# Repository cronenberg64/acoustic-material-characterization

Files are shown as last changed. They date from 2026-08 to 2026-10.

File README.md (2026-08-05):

# Acoustic Material Characterization

This repository contains the software and firmware pipeline for characterizing material properties (such as density and Young's modulus) by analyzing acoustic impact sounds. 

The system relies on a physical testing rig (an ESP32-controlled solenoid) to strike material samples. The resulting acoustic waveform is captured, processed using physics-based modal feature extraction (identifying resonant frequencies and damping coefficients), and passed through a machine learning classifier to predict the material's properties.

## Scientific Objectives
This project bridges the gap between robotic perception (which currently predicts categorical labels under controlled contact) and non-destructive testing (which predicts continuous physical properties using expensive lab apparatus). Our **headline objective** is to prove that a robot can predict continuous physical properties (Density and Young's Modulus) from acoustic impacts, robust to real-world variations in contact location and force.

**Research Questions:**
- **RQ1:** Can we perform accurate property regression (Density, Stiffness) under a leave-one-sample-out evaluation?
- **RQ2:** How well does property estimation generalize across contact variation (held-out force levels and held-out strike positions)?
- **RQ3:** Which acoustic feature families (modal vs. generic) are most resilient to contact variation?

## Getting Started

This project uses `uv` for lightning-fast Python package management. 

### 1. Install Dependencies
```bash
uv sync
```

### 2. Run the Machine Learning Harness
You can test the machine learning pipeline (Random Forest, K-Nearest Neighbors, Ridge Regression, etc.) without needing the physical rig.

**To run on perfectly synthesized acoustic data:**
```bash
uv run python -m ame.models.run_all --dataset synthetic
```

**To run a sanity check on real-world impact data (RealImpact Dataset):**
First, download and extract the RealImpact zip files into `RealImpact/dataset/`. Then run:
```bash
uv run python src/ame/data/import_real_impact.py --dir RealImpact/dataset
uv run python -m ame.models.run_all --dataset internet
```

## Data Acquisition (DAQ)

Once the physical rig is built (ESP32 + Solenoid + Microphone), you can use the DAQ scripts to collect real acoustic samples.

### Calibrate the Solenoid
Determines the correct pulse widths to achieve 5N, 10N, and 15N impact forces.
```bash
uv run python src/ame/daq/calibrate.py --port /dev/cu.usbserial-XXXX
```

### Run an Acquisition Session
Automatically iterates through sample IDs, strike locations, and force levels to build a comprehensive dataset.
```bash
uv run python src/ame/daq/acquire.py --port /dev/cu.usbserial-XXXX
```
*(Note: If no ESP32 is connected, the scripts will gracefully fall back to a mock/synthetic generation mode.)*

## Pipeline Architecture

1. **`ame.daq`**: Handles serial communication with the ESP32 to trigger the solenoid and records the microphone input.
2. **`ame.synth`**: A physics engine that generates realistic damped-sinusoid acoustic waveforms based on theoretical Hertzian impact models for software testing.
3. **`ame.features`**: Extracts both generic audio features (RMS, Zero-Crossing Rate, Spectral Centroid) and modal physics features (Peaks, Damping, Q-Factor).
4. **`ame.models`**: The Scikit-Learn evaluation harness that cross-validates regressors and classifiers on the extracted features.

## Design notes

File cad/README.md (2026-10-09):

# CAD

| Folder | Contents |
|---|---|
| `rig/structure/` | `base_board`, `tier_a_foundation`, `tier_b_spring_bay` (PLA) |
| `rig/electronics/` | `tier_c_deck` (PLA), `tier_d_lid` (PETG) |
| `rig/solenoid_fit/` | `tile_bottom_x4`, `tile_top_x4` (PLA); `filler_22_x2_TPU`, `filler_44_x1_TPU` (TPU) |
| `rig/assembly/` | `tower_v5_assembly.step` |
| `specimens/` | `sample_100x20x8`, `bend_jig` |
| `strikers/` | `striker_cap_14/16/18mm`, `striker_caps` |
| `docs/` | solenoid specs, design sketch, renders |
| `src/` | `generate_tower_v5.py` regenerates everything in `rig/` |

Filename suffix `_xN` = how many to print. Tiles: any split of 4 tiles between bottom and top sets the tap gap (2 + 2 = nominal 15.44 mm).

Print order: `base_board`, `tier_a_foundation`, tiles + fillers, `tier_b_spring_bay`, `tier_c_deck`, `tier_d_lid`.
Do not fire the solenoid until `tier_b_spring_bay` is bolted on.

Regenerate: `uv run python cad/src/generate_tower_v5.py`

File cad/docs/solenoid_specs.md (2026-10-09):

# Tapper Actuator Hardware Specifications: CHiFJ FJ-Z05

Logged from physical digital caliper measurements on 2026-10-01 (updated with verified kinematics on 2026-10-07).

| Parameter | Caliper Measurement | Nominal / Spec Sheet |
|:---|:---:|:---:|
| **Model** | `CHiFJ FJ-Z05` | JF-Z05 / FJ-Z05 |
| **Operating Voltage** | `12VDC` | 12V DC |
| **Current Draw** | `2.5A` | 2.5A |
| **Rated Force** | `45N` (~4.5 kg) | 45N |
| **Rated Stroke** | `15 mm` | 15 mm |
| **Total Push Rod Length ($L_{\text{rod}}$)** | **86.87 mm** | ~85–90 mm |
| **Body Frame Length ($L_{\text{body}}$)** | **51.09 mm** | 50.0 mm |
| **Body Width (Narrow)** | **24.15 mm** | 25.0 mm |
| **Body Depth (Wide)** | **30.79 mm** | 30.0 mm |
| **Rear Return Spring at Rest ($L_{\text{rear, rest}}$)** | **29.12 mm** | Plunger retracted |
| **Rear Spring Compressed ($L_{\text{rear, comp}}$)** | **11.94 mm** | Plunger fully extended |
| **Push Pin Diameter** | **3.0 mm** (2.95–3.18 mm measured) | 3.0 mm ground steel rod |
| **Mounting Pitch (M3 Tapped Holes)** | **17.9 mm (across) × 34.5 mm (along body)** | 18.0 mm × 35.0 mm nominal |

---

## Derived Kinematic & Stroke Breakdown

* **Front Pin Protrusion at Rest (unpowered):**
  $$L_{\text{pin, rest}} = L_{\text{rod}} - L_{\text{body}} - L_{\text{rear, rest}} = 86.87 - 51.09 - 29.12 = \mathbf{6.66\text{ mm}}$$
* **Actual Mechanical Stroke:**
  $$\Delta z = L_{\text{rear, rest}} - L_{\text{rear, comp}} = 29.12 - 11.94 = \mathbf{17.18\text{ mm}}$$
* **Front Pin Protrusion at Full Extension:**
  $$L_{\text{pin, ext}} = L_{\text{pin, rest}} + \Delta z = 6.66 + 17.18 = \mathbf{23.84\text{ mm}}$$

*(Note: Earlier bench notes mistook the 11.94 mm compressed rear spring length for the front pin protrusion, leading to negative clearance in the legacy carriage design).*

---

## Striker Cap Reach & Air Gap (16 mm Cap)
* Cap Pin Pocket Depth: **7.40 mm**
* Cap Extension past Pin Tip: **16.60 mm**
* **Total Reach at Rest (from solenoid front face):** $6.66 + 16.60 = \mathbf{23.26\text{ mm}}$
* **Total Reach Extended (from solenoid front face):** $23.84 + 16.60 = \mathbf{40.44\text{ mm}}$
* **Unibody Carriage Nominal Air Gap at Rest:** **3.74 mm** above specimen surface ($Z_{\text{bar}} = 5.5\text{ mm}$)
* **Dynamic Headroom on Impact:** **13.44 mm** (prevents internal bottoming out during strike)

---

### Operational Notes
* **Pulse Duration:** Solenoid draws 2.5A at 12V (~30W peak power). Designed for short impulse strikes (5–15 ms pulse from ESP32 via logic-level MOSFET driver).
* **Return Mechanism:** Spring return plunger.

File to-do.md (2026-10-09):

# Project Progression & Action Checklist
**Project:** Acoustic Material Characterization (GR1 Research)  
**Status:** In Progress — Solenoid Mount Redesign & Physical Fabrication  
**Last Updated:** 2026-10-09  
**Progress:** 28 / 78 tasks completed (35.9%)

---

## Schedule & Milestones
| By | Milestone |
|---|---|
| Oct 20 | Rig assembled, Gate G1 passed, remaining PLA/TPU bars printed |
| Nov 3 | All bars weighed, measured, bend-tested (ground truth). Pilot sample through full pipeline (G2) |
| Nov 24 | Full 2,700-tap data collection done |
| Dec 15 | RQ1–RQ3 analysis and figures done |
| Jan 8 | Full draft to Prof. Liu |
| Jan 22 | Revisions done, submitted or submit-ready |

*Note: ROBOMECH's deadline is expected around early February (pattern-based, unconfirmed) and IROS 2027's is March 1, both near the February trip, so the effective deadline is before departure.*

---

## Phase 1: 3D Printing & Physical Rig Fabrication
- [x] **Base Fixture & Bend Jig (Completed):**
  - [x] `cad/base_plate.stl` (old plate, retired; replaced by `cad/rig/structure/base_board.stl`)
  - [x] `cad/specimens/bend_jig.stl` (Printed & Ready ✓)
  - [x] M3 brass heat-set inserts installed in base plate (All 12 holes flush ✓)
- [ ] **Solenoid Carriage & Mount (Redesign Overhaul in Progress):**
  - [x] Retired legacy 2-piece design (32 mm legs starved screw threads, trapped nuts, blocked rear holes)
  - [x] Retired Carriage v4 (`cad/solenoid_carriage_v4.stl` — toppling solenoid, difficult fastener access)
  - [ ] **New Carriage Redesign**:
    - [ ] Review user's sketches and design overhaul inputs
    - [ ] Incorporate physical resting cradle / ledge so solenoid cannot topple during assembly
    - [ ] Solve solenoid clamping / fastening (accessible screws/clamp, zero coil puncture risk)
    - [ ] Maintain open line-of-sight counterbores for base plate M3×12 mm screws into brass inserts
    - [ ] Maintain positive air gap (~15.4 mm rest gap, 17.4 mm stroke)
    - [ ] Generate parametric CadQuery script, STL, STEP, and test suite
    - [ ] 3D print the new carriage
- [x] **Striker Caps & Solenoid Hardware Prep:**
  - [x] Ground-truth digital caliper measurements verified:
    - Total rod: 86.87 mm | Body: 51.09 mm | Body width: 24.15 mm | Depth: 30.79 mm
    - Spring at rest: 29.12 mm | Spring compressed: 11.94 mm | Pin dia: 3.0 mm
    - Stroke: 17.18–17.44 mm | Rest reach (16mm cap): 26.11 mm | Energized reach: 43.55 mm
  - [x] 16 mm Striker cap printed and fitted onto plunger pin ✓
  - [x] Hardware gathered strictly from Kinzomoor 500-pc kit (`[6, 8, 12, 16, 20] mm` SHCS + M3 flat washers + M3 nuts)
  - [ ] Check 2020 extrusion slot width (5 mm vs 6 mm) for T-nuts
  - [ ] Decide strike tip: steel ball glued into the cap vs printed dome
- [ ] **Specimen Beams Print Status:**
  - [x] PLA 100% bar printed (`cad/specimens/sample_100x20x8.stl` ✓)
  - [x] TPU 60% bar printed ✓
  - [ ] Print remaining PLA bars (80%, 60% ×3 as PLA-60 / -R1 / -R2, 40%, 20%)
  - [ ] Print TPU-100
  - [ ] Procure PETG filament spool (covers intermediate stiffness between PLA and TPU)
  - [ ] Print PETG specimen batch (after filament arrives: 20%, 40%, 60%, 80%, 100%)

---

## Phase 2: Electronics & Firmware Bench Validation
- [x] **Solenoid Driver Circuit (Verified ✓):**
  - [x] Wire 12V DC power supply into Freenove breakout board barrel jack
  - [x] Route regulated power & GND to IRF520 MOSFET module
  - [x] Wire solenoid to MOSFET load terminals
  - [x] Connect ESP32 D4 (GPIO 4) to MOSFET SIG and common GND
  *(Note: "Verified ✓" confirms the solenoid fires, not that force is repeatable; repeatability is measured in the 50-tap test)*
- [x] **ESP32 Firmware (Flashed & Tested ✓):**
  - [x] PlatformIO setup in `.venv`
  - [x] Patch firmware for non-blocking HX711 checks
  - [x] Flash firmware: `uv run pio run -d firmware/esp32_tapper -t upload --upload-port /dev/cu.usbserial-10`
  - [x] Verify bench pulses: TAP 1 (5000 µs), TAP 2 (10000 µs), TAP 3 (15000 µs) fired with 100% success ✓
- [ ] **Wiring & Repeatability Checks:**
  - [ ] Wiring check: solenoid current path bypasses breadboard and ESP32 board, ≥22 AWG
  - [ ] Tap repeatability test: 50 taps at fixed pulse width, check peak amplitude stability and MOSFET temp (Gate G1)
  - [ ] CONDITIONAL (if amplitude spread >~10%): Swap for D4184 logic-level MOSFET module or add buffer capacitor

---

## Phase 3: Specimen Fabrication & Ground-Truth Measurement
- [ ] **Measure Specimen Beams (100 x 20 x 8 mm):**
  - [ ] Measure exact L, b, h with digital caliper (±0.05 mm)
  - [ ] Weigh each beam on digital scale (±0.01 g) to calculate true density rho
- [ ] **3-Point Bend Static Test (Mechanical Ground Truth):**
  - [ ] Place beam on `bend_jig` fulcrums (span L_s = 80 mm)
  - [ ] Apply step loads with weights / load cell and measure deflection delta
  - [ ] Run `src/ame/analysis/ground_truth.py` to extract Young's modulus E

---

## Phase 4: Acoustic Data Acquisition (DAQ) & Calibration
- [ ] **Gates & Pre-Checks:**
  - [ ] Hand-tap pre-check: record the PLA 100% bar on nodal ridges, confirm distinct modal peaks
  - [ ] **Gate G1**: 50 taps, 1 sample, 1 condition, modal peaks stable within a few %
  - [ ] **Gate G2**: pilot sample, full 9-condition grid × 20 reps, through DAQ → features → harness end-to-end
- [ ] **Rig Assembly & Setup:**
  - [ ] Bolt base plate to 2020 aluminum extrusion rails
  - [ ] Mount newly redesigned solenoid carriage on base plate at position 1 (X = 0 mm)
  - [ ] Place specimen on nodal support ridges (X = ±27.6 mm)
  - [ ] Attach acoustic sensor (piezo / contact mic / Analog Discovery 3)
- [ ] **Strike Angle & Position Calibration:**
  - [ ] Test normal impact (0 deg) at 3 span positions (X = 0, 22, 44 mm)
  - [ ] Verify acoustic waveform SNR and strike repeatability via `src/ame/daq/acquire.py`

---

## Phase 5: Machine Learning & Scientific Evaluation
- [ ] Extract modal frequencies (f1, f2, f3) and acoustic damping (zeta)
- [ ] Train regression models (KNN, Random Forest, Ridge) via `src/ame/models/run_all.py`
- [ ] Cross-validate predicted stiffness (E) and density (rho) against ground truth
- [ ] Produce comparative figures and tables for final GR1 publication report

---

## Phase 6: Writing & Submission
- [ ] Full draft to Prof. Liu (target Jan 8)
- [ ] Revisions after review (target Jan 22)
- [ ] Choose venue by fit and confirm its deadline on the official site
- [ ] Submit before the February trip
- [ ] Repo README + scripts that regenerate every figure from raw data

---

## Deferred / Parked
- [ ] ±15° angle tests (RQ2 grid is 3 forces × 3 positions; revisit if time allows)
- [ ] Angle index pin for the pivot mount (the detent holes don't actually lock the angle)

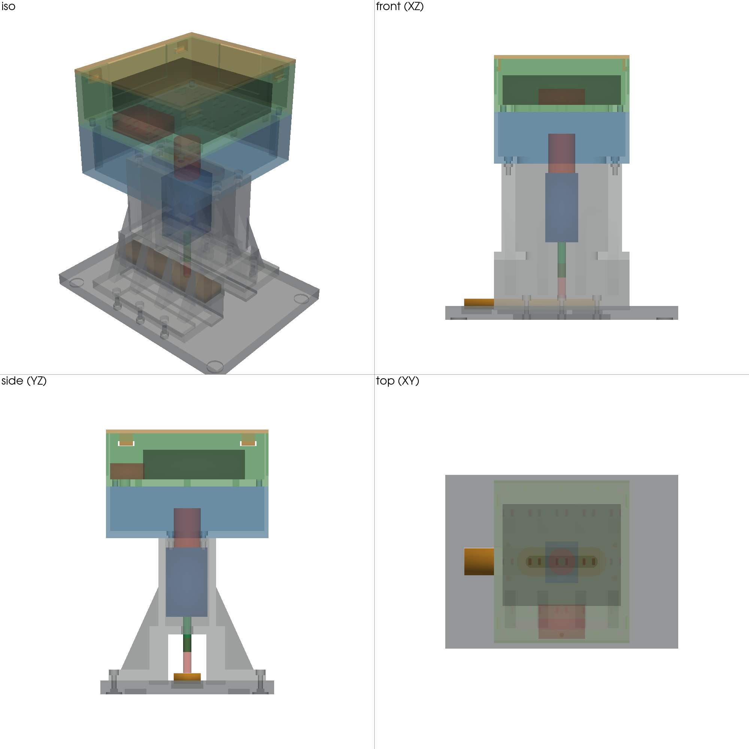
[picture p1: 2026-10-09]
cad/renders/full-rig-schematic.png

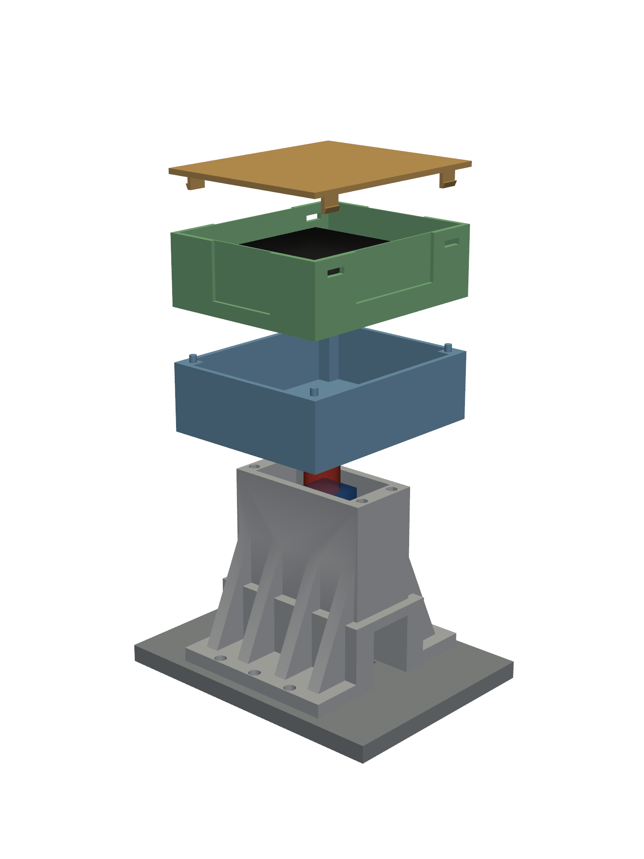
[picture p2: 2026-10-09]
cad/renders/full-rig-layers.png

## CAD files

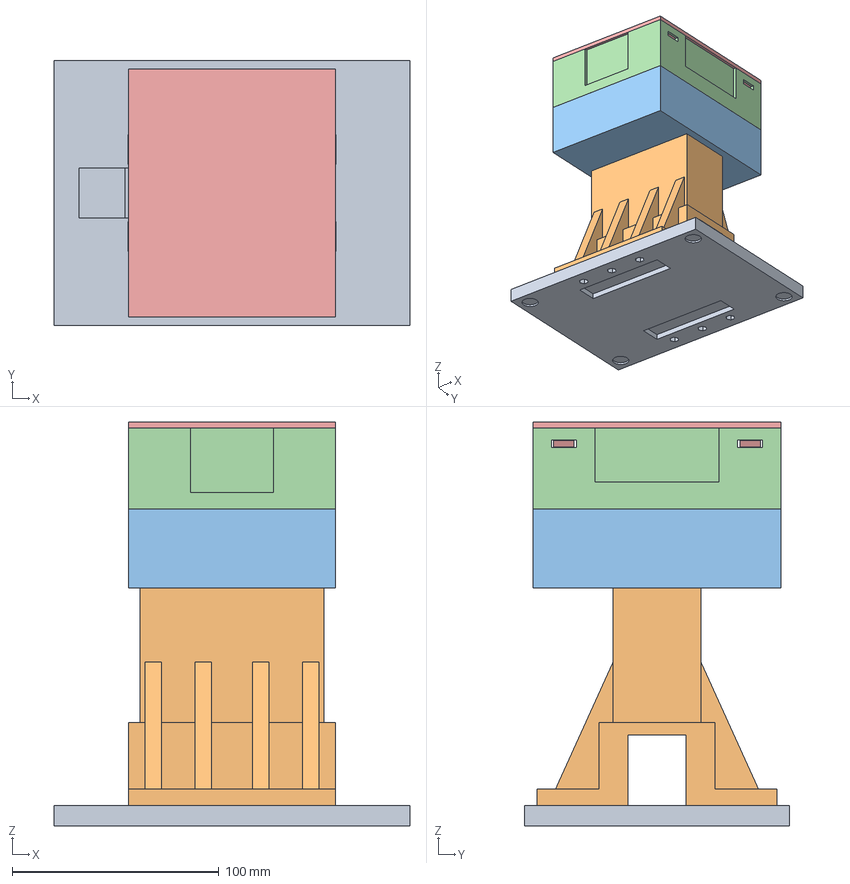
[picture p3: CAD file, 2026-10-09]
cad/rig/assembly/full_assembly.step
172.0 x 128.0 x 195.3 mm
base_board
tier_a_foundation
tier_b_spring_bay
tier_c_deck
tier_d_lid

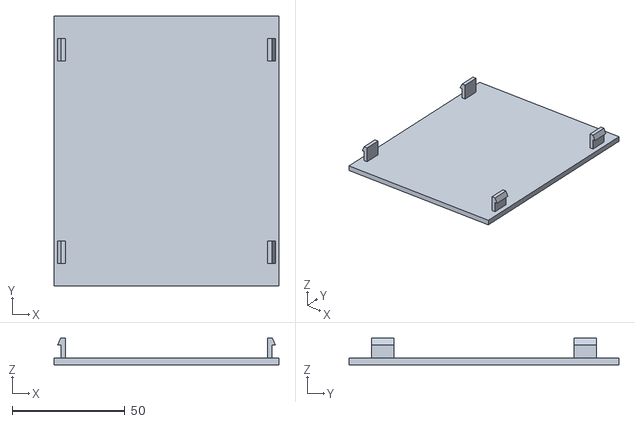
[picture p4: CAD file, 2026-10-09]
cad/rig/electronics/tier_4_lid.stl
100.0 x 120.0 x 12.0

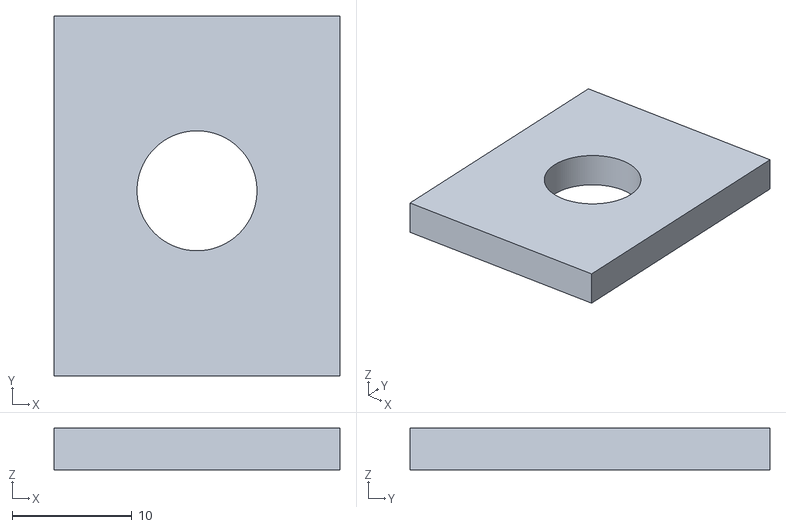
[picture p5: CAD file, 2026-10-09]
cad/rig/solenoid_fit/tile_bottom_x4.stl
23.9 x 30.0 x 3.50

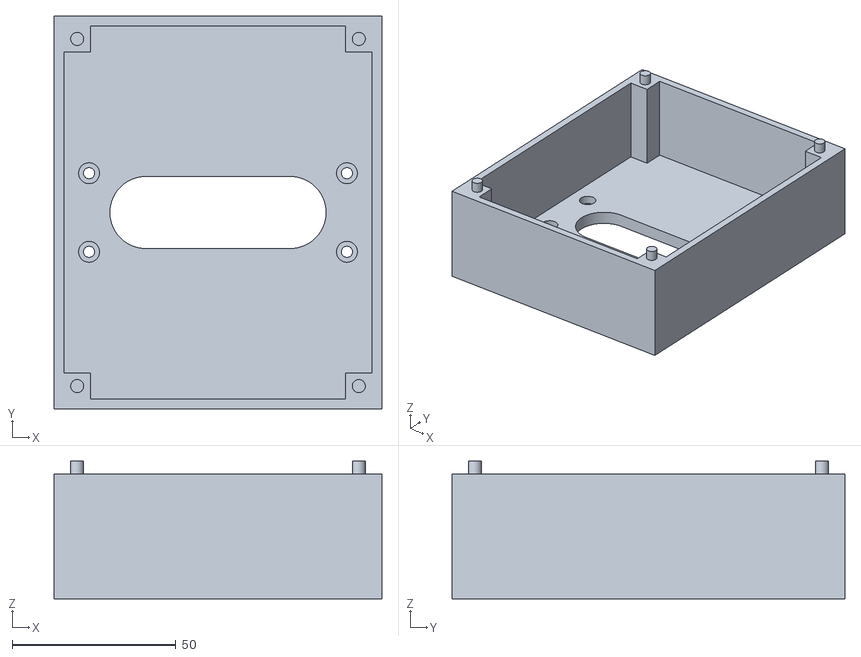
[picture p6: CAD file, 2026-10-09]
cad/rig/structure/tier_2_spring_chamber.stl
100.0 x 120.0 x 42.1

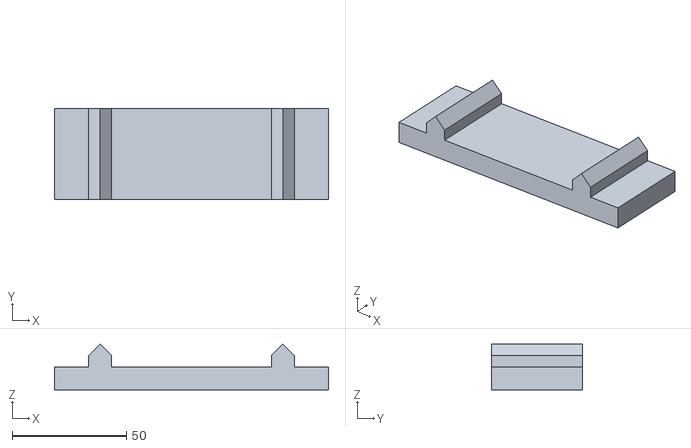
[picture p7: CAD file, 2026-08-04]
cad/specimens/bend_jig.stl
120.0 x 40.0 x 20.0

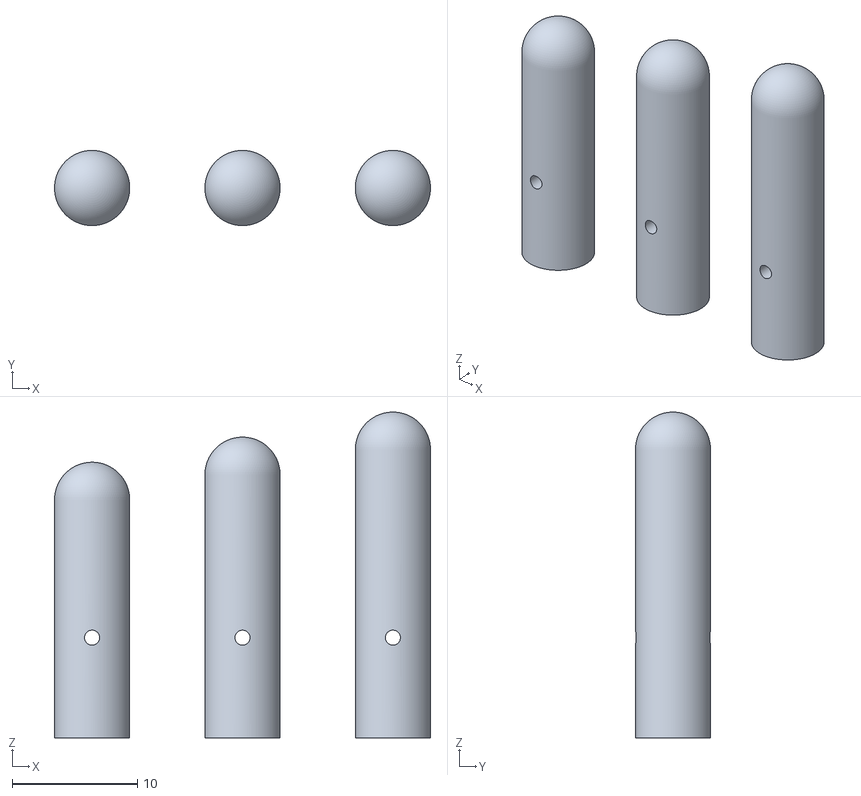
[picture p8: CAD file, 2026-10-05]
cad/strikers/striker_caps.stl
30.0 x 6.00 x 26.0

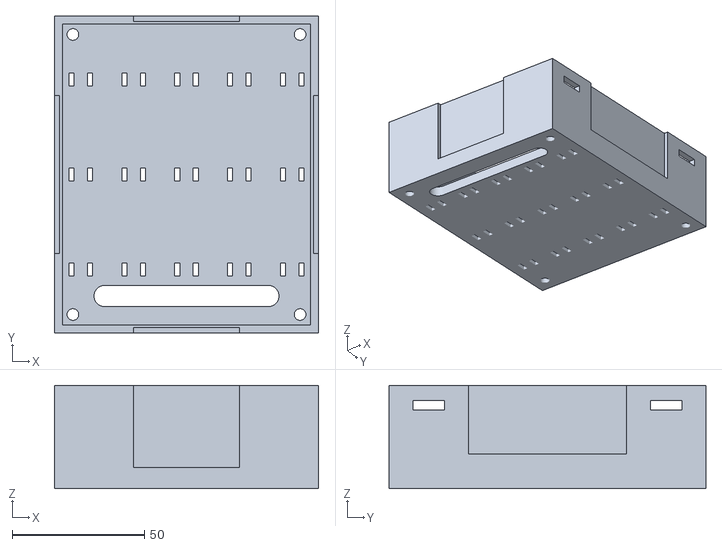
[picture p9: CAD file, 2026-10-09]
cad/rig/electronics/tier_3_deck.stl
100.0 x 120.0 x 39.0

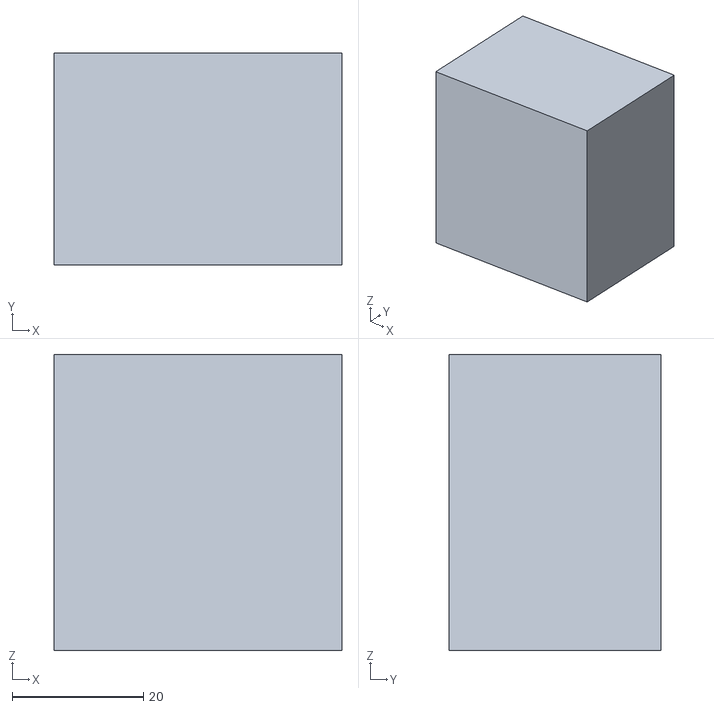
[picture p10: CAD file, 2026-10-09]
cad/rig/solenoid_fit/filler_44_x1_TPU.stl
43.8 x 32.3 x 45.1

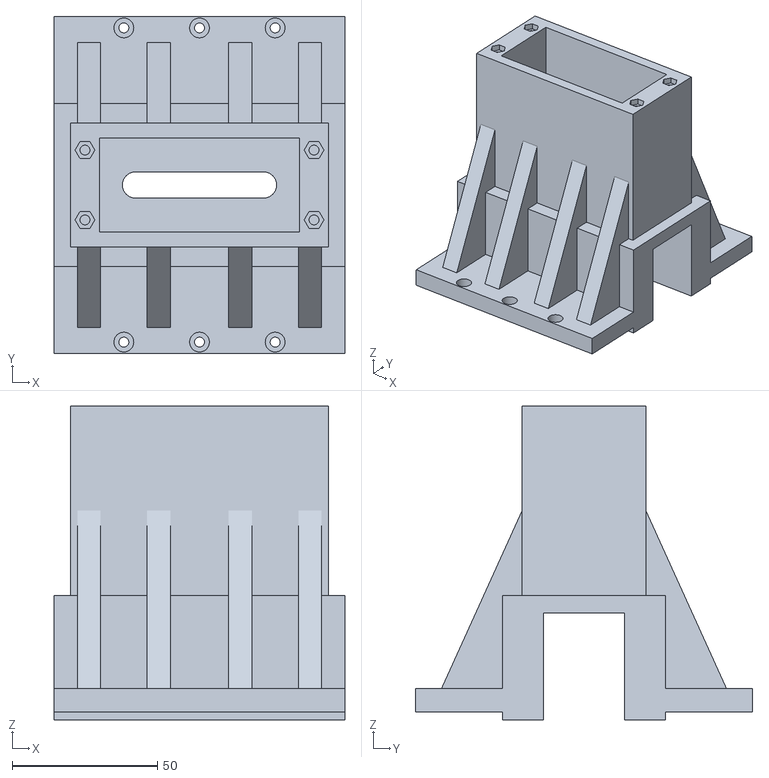
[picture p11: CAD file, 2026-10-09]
cad/rig/structure/tier_1_foundation.stl
100.0 x 116.0 x 107.9

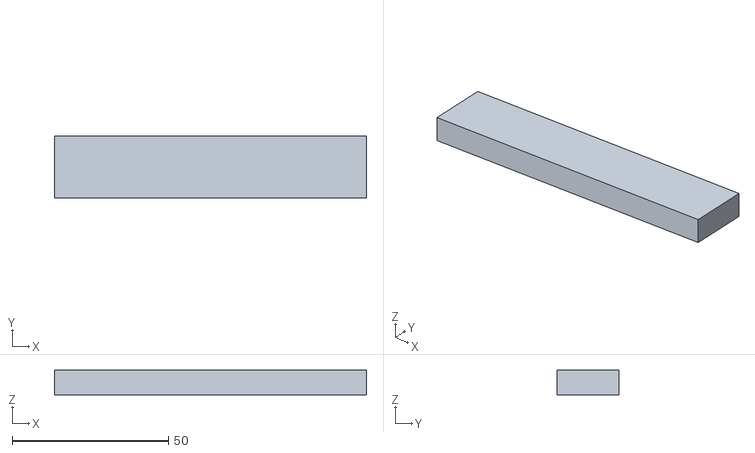
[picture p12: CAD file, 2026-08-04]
cad/specimens/sample_100x20x8.stl
100.0 x 20.0 x 8.00

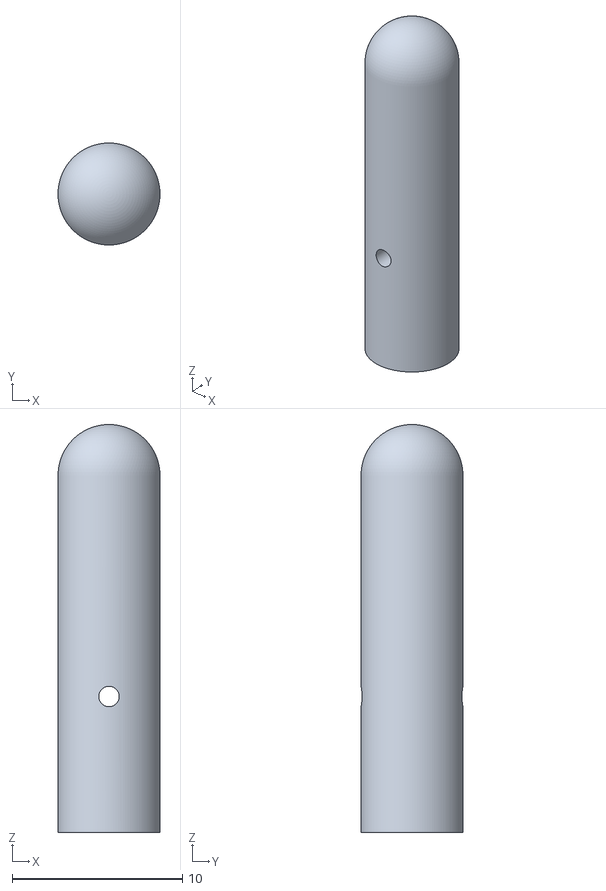
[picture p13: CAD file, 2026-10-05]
cad/strikers/striker_cap_16mm.stl
6.00 x 6.00 x 24.0

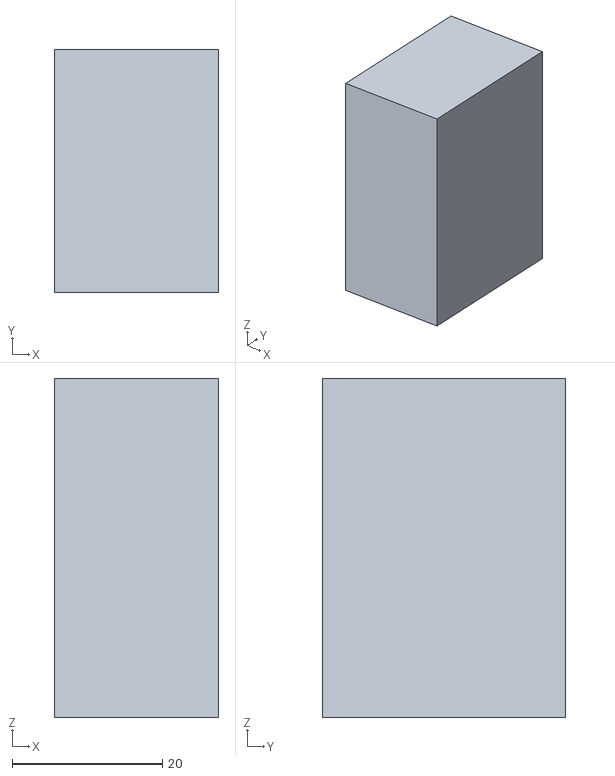
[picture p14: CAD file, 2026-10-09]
cad/rig/solenoid_fit/filler_22_x2_TPU.stl
21.9 x 32.3 x 45.1

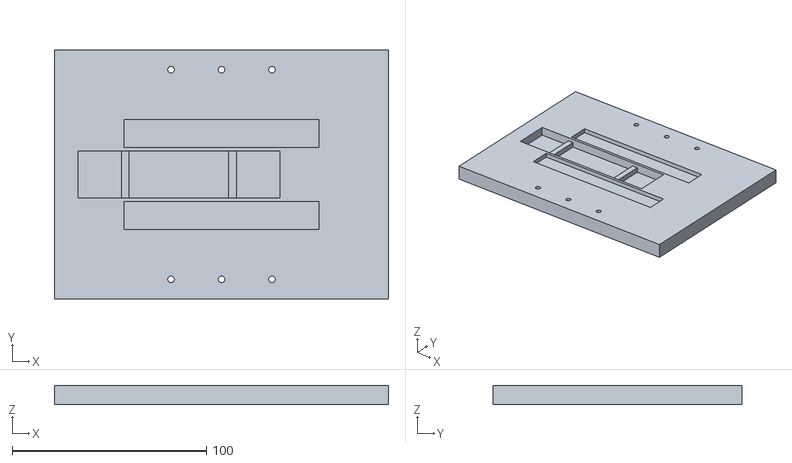
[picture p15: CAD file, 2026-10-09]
cad/rig/structure/base_board.stl
172.0 x 128.0 x 10.0

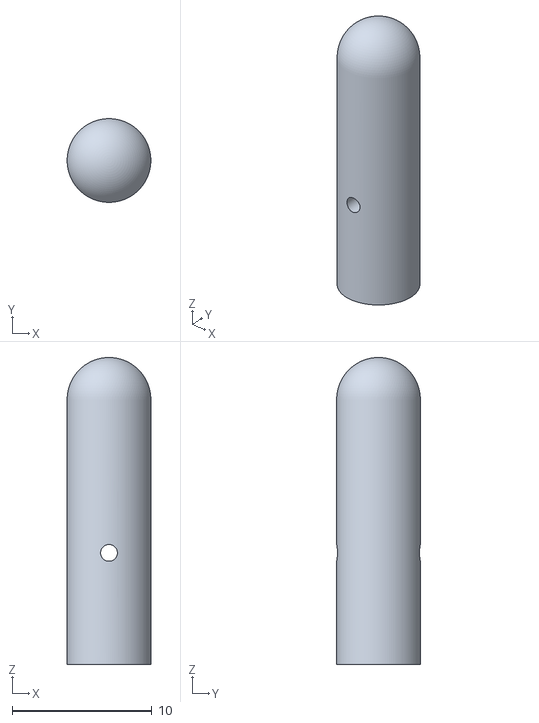
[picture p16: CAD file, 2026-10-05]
cad/strikers/striker_cap_14mm.stl
6.00 x 6.00 x 22.0

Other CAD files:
cad/rig/solenoid_fit/tile_top_x4.stl
cad/strikers/striker_cap_18mm.stl

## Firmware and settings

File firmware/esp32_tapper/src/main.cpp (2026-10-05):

#include <Arduino.h>
#include <ArduinoJson.h>
#include "HX711.h"

// Pin Definitions
const int SOLENOID_PIN = 4;
const int TRIGGER_PIN = 2; // Sent to DAQ
const int HX711_DOUT_PIN = 16;
const int HX711_SCK_PIN = 17;

// HX711 Load Cell
HX711 scale;
float calibration_factor = -105.0; 

// State
unsigned long last_tap_time = 0;
const unsigned long MIN_INTER_TAP_MS = 500;

// Pulse width configurations based on calibration (mock values for now)
unsigned long pw_level_1 = 5000;
unsigned long pw_level_2 = 10000;
unsigned long pw_level_3 = 15000;
unsigned long current_pw = pw_level_1;

void setup() {
  Serial.begin(115200);
  
  pinMode(SOLENOID_PIN, OUTPUT);
  digitalWrite(SOLENOID_PIN, LOW);
  
  pinMode(TRIGGER_PIN, OUTPUT);
  digitalWrite(TRIGGER_PIN, LOW);
  
  scale.begin(HX711_DOUT_PIN, HX711_SCK_PIN);
  scale.set_scale(calibration_factor);
  if (scale.wait_ready_timeout(100)) {
    scale.tare(); // Reset the scale to 0
  }
  
  Serial.println("{\"status\": \"ready\"}");
}

void fire_solenoid(unsigned long pulse_width_us) {
  // Fire pulse & trigger pulse simultaneously
  digitalWrite(TRIGGER_PIN, HIGH);
  digitalWrite(SOLENOID_PIN, HIGH);
  
  delayMicroseconds(pulse_width_us);
  
  digitalWrite(SOLENOID_PIN, LOW);
  digitalWrite(TRIGGER_PIN, LOW);
}

void process_command(String cmd) {
  cmd.trim();
  StaticJsonDocument<256> doc;
  
  if (cmd.startsWith("TAP")) {
    int level = cmd.substring(4).toInt();
    
    if (millis() - last_tap_time < MIN_INTER_TAP_MS) {
      doc["error"] = "Thermal protection: tap too soon";
    } else {
      unsigned long pw = current_pw;
      if (level == 1) pw = pw_level_1;
      else if (level == 2) pw = pw_level_2;
      else if (level == 3) pw = pw_level_3;
      
      // Measure preload if scale is connected
      float preload = 0.0;
      if (scale.wait_ready_timeout(50)) {
        preload = scale.get_units(3);
      }
      
      // Fire
      fire_solenoid(pw);
      last_tap_time = millis();
      
      // We cannot read HX711 fast enough for impact peak (80 SPS max).
      // So we report preload and the configured level.
      doc["tap_success"] = true;
      doc["level"] = level;
      doc["pulse_width_us"] = pw;
      doc["peak_force"] = preload; // (mocked as preload)
    }
  } 
  else if (cmd.startsWith("SET_PW")) {
    current_pw = cmd.substring(7).toInt();
    doc["pw_set"] = current_pw;
  }
  else if (cmd.equals("TARE")) {
    if (scale.wait_ready_timeout(100)) {
      scale.tare();
      doc["tared"] = true;
    } else {
      doc["tared"] = false;
      doc["warning"] = "HX711 not ready";
    }
  }
  else if (cmd.equals("READ_FORCE")) {
    if (scale.wait_ready_timeout(100)) {
      doc["force"] = scale.get_units(5);
    } else {
      doc["force"] = 0.0;
      doc["warning"] = "HX711 not ready";
    }
  }
  else if (cmd.equals("STATUS")) {
    doc["ready"] = true;
  }
  else if (cmd.equals("ID")) {
    doc["device"] = "ESP32_Tapper";
    doc["version"] = "1.0.0";
  }
  else {
    doc["error"] = "Unknown command";
  }
  
  doc["timestamp_ms"] = millis();
  serializeJson(doc, Serial);
  Serial.println();
}

void loop() {
  if (Serial.available()) {
    String command = Serial.readStringUntil('\n');
    process_command(command);
  }
}

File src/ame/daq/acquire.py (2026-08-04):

import os
import uuid
import datetime
import time
import argparse
import numpy as np
import pandas as pd
import soundfile as sf
import serial
from typing import Dict, Any

from ame.schema import TapRecord
from ame.synth.generator import generate_tap_waveform

try:
    from pydwf import DwfLibrary, DwfEnumConfigInfo, DwfAcquisitionMode, DwfTriggerSource, DwfTriggerSlope
except ImportError:
    pass

class DAQMock:
    """Mock DAQ using the synthetic generator."""
    def __init__(self, sample_rate: int = 192000, duration: float = 0.3):
        self.sample_rate = sample_rate
        self.duration = duration
        
    def configure(self):
        print("mock daq configured.")
        
    def wait_for_trigger_and_read(self) -> np.ndarray:
        print("mock daq triggered. generating synthetic wave...")
        time.sleep(0.1) # Simulate acquisition time
        # Return a synthetic tap wave
        wave, _ = generate_tap_waveform(
            youngs_modulus=3.5e9, 
            density=1240.0, 
            geometry_scale=0.1, 
            force_level=2, 
            position_id=1, 
            angle_deg=0.0,
            sr=self.sample_rate,
            duration=self.duration
        )
        return wave
        
class DAQHardware:
    """Real DAQ interfacing with Analog Discovery 3 via pydwf."""
    def __init__(self, sample_rate: int = 1000000, duration: float = 0.3):
        self.sample_rate = sample_rate
        self.duration = duration
        self.num_samples = int(self.sample_rate * self.duration)
        self.dwf = DwfLibrary()
        self.device = None
        
    def configure(self):
        # Open first available device
        self.device = self.dwf.deviceControl.open(-1)
        self.ain = self.device.analogIn
        
        # Configure channels
        self.ain.channelEnableSet(0, True) # Piezo
        self.ain.channelEnableSet(1, True) # Trigger from ESP32
        
        self.ain.channelRangeSet(0, 5.0) # +/- 5V
        self.ain.channelRangeSet(1, 5.0)
        
        # Acquisition
        self.ain.acquisitionModeSet(DwfAcquisitionMode.Record)
        self.ain.frequencySet(float(self.sample_rate))
        self.ain.recordLengthSet(self.duration)
        
        # Trigger on Channel 1 (ESP32 pulse) rising edge
        self.ain.triggerSourceSet(DwfTriggerSource.DetectorAnalogIn)
        self.ain.triggerChannelSet(1)
        self.ain.triggerLevelSet(2.0) # 2V threshold
        self.ain.triggerConditionSet(DwfTriggerSlope.Rise)
        
        # Pre-trigger 10ms
        self.ain.triggerPositionSet(0.01)
        
    def wait_for_trigger_and_read(self) -> np.ndarray:
        self.ain.configure(False, True)
        
        while True:
            status = self.ain.status(True)
            if status == 2: # DwfStateDone
                break
            time.sleep(0.001)
            
        data = self.ain.statusData(0, self.num_samples)
        return np.array(data)
        
    def close(self):
        if self.device:
            self.device.close()


def check_signal_quality(waveform: np.ndarray, max_val: float = 5.0) -> bool:
    """Quality checks: clipping, flat-line, SNR."""
    if np.all(waveform == waveform[0]):
        print("error: flat-line detected in signal.")
        return False
        
    if np.max(np.abs(waveform)) >= (max_val - 0.05):
        print("error: clipping detected.")
        return False
        
    rms = np.sqrt(np.mean(waveform**2))
    peak = np.max(np.abs(waveform))
    if peak / rms < 2.0: # Very low crest factor means it might be mostly noise
        print("error: low snr detected (mostly noise).")
        return False
        
    return True

def record_tap(daq, esp_serial: serial.Serial, metadata: dict, output_dir: str) -> TapRecord:
    if esp_serial:
        esp_serial.write(f"TAP {metadata['force_level']}\n".encode())
    
    waveform = daq.wait_for_trigger_and_read()
    
    if not check_signal_quality(waveform):
        raise RuntimeError("Signal quality check failed. Aborting collection.")
        
    sample_dir = os.path.join(output_dir, metadata['sample_id'])
    os.makedirs(sample_dir, exist_ok=True)
    
    uid = str(uuid.uuid4())
    fpath = os.path.join(sample_dir, f"{uid}.wav")
    sf.write(fpath, waveform, metadata['sample_rate_hz'])
    
    metadata['waveform_path'] = fpath
    metadata['timestamp'] = datetime.datetime.now(datetime.timezone.utc).isoformat()
    metadata['measured_peak_force_N'] = metadata['force_level'] * 5.0 # Mocked for now
    
    return TapRecord(**metadata)

def run_session(config: Dict[str, Any], mock: bool = False):
    out_dir = config.get("output_dir", "data/raw")
    os.makedirs(out_dir, exist_ok=True)
    
    if mock:
        daq = DAQMock(sample_rate=192000)
        esp = None
    else:
        daq = DAQHardware(sample_rate=192000)
        esp = serial.Serial('/dev/ttyUSB0', 115200, timeout=1)
        
    daq.configure()
    
    samples = config.get("samples", ["PLA_30_1"])
    forces = config.get("forces", [1, 2, 3])
    positions = config.get("positions", [1, 2, 3])
    reps = config.get("reps", 5)
    
    records = []
    
    try:
        for sample in samples:
            input(f"Operator: Please mount sample {sample} and press Enter...")
            
            for pos in positions:
                input(f"Operator: Adjust tapper to position {pos} and press Enter...")
                
                for force in forces:
                    for rep in range(reps):
                        print(f"recording {sample} | pos: {pos} | force: {force} | rep: {rep+1}/{reps}")
                        
                        meta = {
                            "sample_id": sample,
                            "material": sample.split("_")[0],
                            "infill_pct": int(sample.split("_")[1]),
                            "force_level": force,
                            "position_id": pos,
                            "angle_deg": 0.0,
                            "tip_id": "standard",
                            "rep_index": rep,
                            "sample_rate_hz": 192000,
                            "density_kgm3": None,
                            "youngs_modulus_pa": None
                        }
                        
                        record = record_tap(daq, esp, meta, out_dir)
                        records.append(record.model_dump())
                        
                        time.sleep(0.5) # Inter-tap interval
    except KeyboardInterrupt:
        print("\nsession aborted by user.")
    finally:
        if not mock:
            daq.close()
            esp.close()
            
        if records:
            df = pd.DataFrame(records)
            df.to_csv(os.path.join(out_dir, "metadata_session.csv"), index=False)
            print(f"saved {len(records)} records.")
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

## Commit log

2026-08-04 implement initial project scaffold
    Add initial project scaffold for acoustic material characterization. Includes Python package (pyproject.toml), core library under src/ame (DAQ interfaces, synthetic data generator, feature extraction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
2026-08-04 Add external dataset eval, schema, and logs
    Add support for evaluating externally-sourced audio (e.g., RealImpact) and small housekeeping updates.
    - src/ame/models/run_all.py: add librosa import, CLI flag (--dataset) and run_external_evaluation() to load external metadata, extract features, and run a simple RandomForest classification (accuracy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
    - src/ame/schema.py: introduce Optional typing adjustments and new ExternalAudioRecord Pydantic model to represent externally-sourced audio metadata and keep it separated from rig measurements.
    - src/ame/daq/acquire.py, src/ame/daq/calibrate.py, src/ame/synth/generator.py, src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
2026-08-04 Add CAD files, models, ground-truth analysis
    [base_plate.stl, bend_jig.stl, sample_100x20x8.stl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]
2026-08-05 add ground truth calculation
2026-10-01 fix cad files
    [solenoid_carriage.stl]
2026-10-05 add striker cap CAD models, project checklist, and update firmware for esp32
    [striker_cap_14mm.stl, striker_cap_16mm.stl, striker_cap_18mm.stl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]
2026-10-09 redesign carriage
    [solenoid_carriage_pivot_carriage.stl, solenoid_carriage_pivot_plate.stl, solenoid_carriage_v4.stl]
2026-10-09 reorganize CAD directory structure and add documentation for new rig assembly and components
    [base_board.stl, base_plate.stl, bend_jig.stl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]
2026-10-15 update CAD models, add assembly documentation, and include render assets
2026-10-15 update CAD models, renders, and documentation for screwless stand assembly and revised part geometries
